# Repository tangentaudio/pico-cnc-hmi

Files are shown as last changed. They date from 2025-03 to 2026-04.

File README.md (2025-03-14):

# pico-cnc-hmi
Open source and open hardware HMI for LinuxCNC using USB Raw HID on a Raspberry Pi Pico 2.

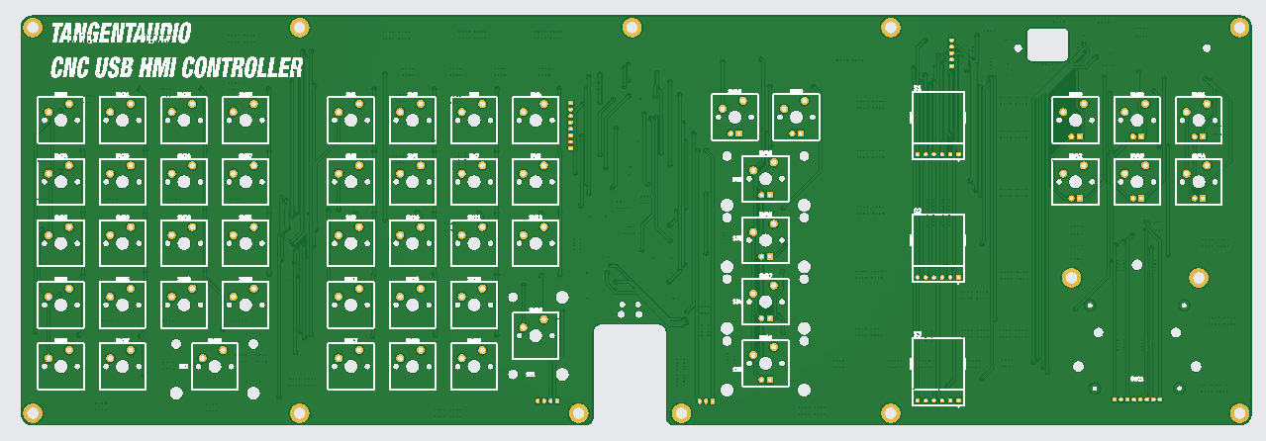
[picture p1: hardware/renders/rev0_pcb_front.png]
REV0 PCB Render Front

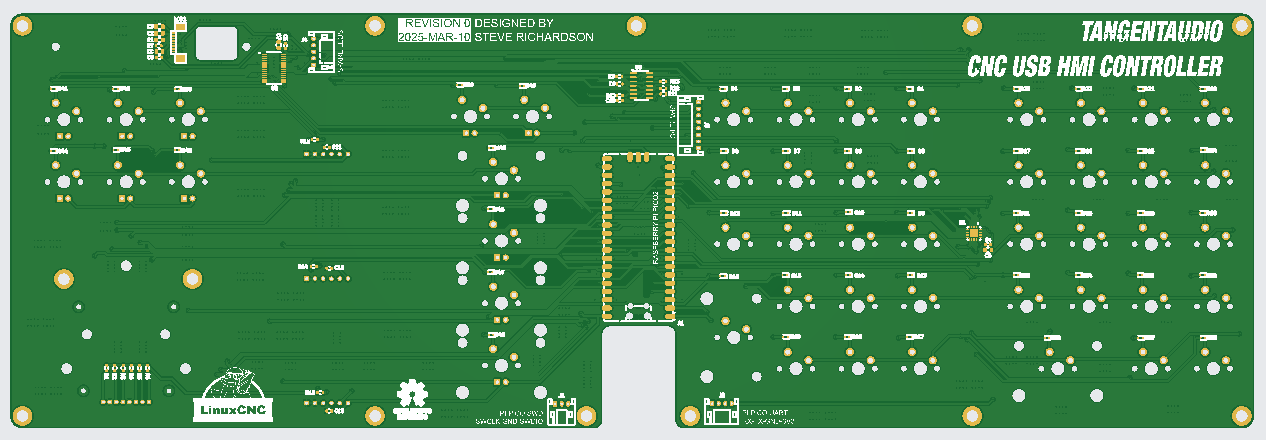
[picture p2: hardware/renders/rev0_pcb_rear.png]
REV0 PCB Render Rear


# News

- rev0 PCB sent to fabrication on 2025-MAR-10.

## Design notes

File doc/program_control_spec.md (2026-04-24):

# Pico CNC HMI — Program Control Specification

## 1. Overview

This document specifies the desired behavior of the four program control buttons
on the HMI: **STOP**, **PAUSE**, **CYCLE START**, and **SINGLE STEP**. It also
covers their interaction with LinuxCNC's mode and interpreter state.

> [!IMPORTANT]
> **Design Principle:** The HMI must never initiate unexpected machine motion.
> Only CYCLE START may start or resume motion. All other transitions leave the
> machine stationary.

---

## 2. LinuxCNC State Primer

### Modes (task_mode)
| Value | Name | Notes |
|---|---|---|
| 1 | MANUAL | Jog, home |
| 2 | AUTO | Program execution, step, pause, resume |
| 3 | MDI | Manual Data Input (Probe Basic uses this frequently) |

### Task State (s.state / RCS status)
| Constant | Meaning |
|---|---|
| `RCS_DONE` | Task is idle (not executing anything) |
| `RCS_EXEC` | Task is executing (program running, stepping, or paused mid-program) |
| `RCS_ERROR` | Task encountered an error |

> [!IMPORTANT]
> `s.state == RCS_EXEC` remains true even when a program is **paused**.
> This is how QtPyVCP detects "paused mid-program" vs "truly idle":
> `RCS_EXEC and s.paused`.

### Interpreter States (interp_state)
| Value | Name | Meaning |
|---|---|---|
| 1 | IDLE | No program activity |
| 2 | READING | Interpreter is reading/executing G-code lines |
| 3 | PAUSED | Program paused (by AUTO_PAUSE or between steps) |
| 4 | WAITING | Waiting for motion/IO to complete |

### Pause-Related Fields
| Field | Type | Meaning |
|---|---|---|
| `s.paused` | bool | Motion trajectory paused (`motion.traj.paused`) |
| `s.task_paused` | int | Task-level paused flag (`task.task_paused`) |

> [!WARNING]
> `interp_state == INTERP_PAUSED` is NOT the only way LinuxCNC can be "paused."
> After an `AUTO_STEP`, the interpreter may settle in `INTERP_READING` or
> `INTERP_WAITING` with `task_paused=1` and `paused=True`. Our code must use
> `s.paused` (or `s.state == RCS_EXEC and s.paused`) as the canonical "is it
> paused?" check, NOT `interp_state == INTERP_PAUSED`.

### Key LinuxCNC Commands
| Command | Effect |
|---|---|
| `c.auto(AUTO_RUN, 0)` | Start program from line 0 (continuous) |
| `c.auto(AUTO_STEP)` | Execute one block then pause |
| `c.auto(AUTO_PAUSE)` | Pause a running program (immediate deceleration) |
| `c.auto(AUTO_RESUME)` | Resume from pause (continuous) |
| `c.abort()` | Abort program execution |
| `c.mode(MODE_AUTO)` | Switch to AUTO mode (required before program commands) |

---

## 3. HMI State Model

### The Step-Mode Question

LinuxCNC does **not** expose a "step mode" flag. From LinuxCNC's perspective,
`AUTO_STEP` is a one-shot command: "execute one block, then pause." There is no
persistent "step mode" state in LinuxCNC.

**QtPyVCP's approach (Probe Basic's GUI):** Each button press is a simple,
stateless command:
- **Step button** → `CMD.auto(AUTO_STEP)` (no flag, no toggle)
- **Run button** → if `paused`: `AUTO_RESUME`, else: `AUTO_RUN`
- **Pause button** → `AUTO_PAUSE`

Probe Basic does NOT track a step-mode flag. Each step press just advances one
block. The "run" button always resumes continuously. This is simple and robust.

**Our HMI constraint:** We have a dedicated STEP button that we want to act as
a modal toggle (enter/exit step mode). This is a UX choice that goes beyond what
LinuxCNC natively models. We need `hmi_step_mode` because:
1. We want CYCLE START to advance one block when "in step mode" vs resume
   continuously when "not in step mode"
2. We want distinct LED states for step mode vs paused

**Accepted trade-off:** `hmi_step_mode` is HMI-local state that can desync from
LinuxCNC (e.g., on USB reconnect, or if Probe Basic's GUI is used concurrently).
It resets to `False` on reconnect (safe default: resume continuously).

### Logical State Derivation

Rather than mixing raw LinuxCNC fields throughout the command handlers, compute
a single logical state once per cycle:

```python
def compute_logical_state():
    if s.interp_state == INTERP_IDLE:
        return 'IDLE'
    elif hmi_step_mode:
        return 'STEPPING'
    elif s.paused:       # covers interp PAUSED, READING+paused, WAITING+paused
        return 'PAUSED'
    else:
        return 'RUNNING'
```

This collapses the combinatorial explosion into 4 states that map cleanly to
button actions and LED states.

### State Transition Diagram

```
                       STEP from IDLE
                       (sets step_mode=true,
                        issues AUTO_STEP →
┌──────────────┐        executes 1st block)
│     IDLE     │─────────────────────────────┐
│  (STOP lit)  │                             │
└──────┬───────┘                             ▼
       │                              ┌──────────────┐
       │ CYCLE START                  │  STEPPING    │◄──┐
       │ (AUTO_RUN)                   │(STEP+START   │   │
       ▼                              │  blink)      │   │
┌──────────────┐                      └──┬───┬───────┘   │
│   RUNNING    │                        │   │            │
│  (START lit) │          CYCLE START   │   │            │
└──┬───────────┘          (AUTO_STEP) ──┘   │            │
   │                                        │            │
   │ PAUSE                    STEP          │            │
   │ (AUTO_PAUSE)             (toggle off → │            │
   ▼                           step_mode=   │            │
┌──────────────┐               false)       │            │
│    PAUSED    │◄───────────────────────────┘            │
│ (PAUSE blink)│                                         │
└──┬───────────┘                                         │
   │                                                     │
   │ STEP from PAUSED                                    │
   │ (sets step_mode=true, NO command issued,            │
   │  awaits CYCLE START to advance)                     │
   └─────────────────────────────────────────────────────┘

   STOP from any state → IDLE  (c.abort, step_mode=false)
```

**Key distinction:**
- **STEP from IDLE** → enters step mode AND auto-starts first block (`AUTO_STEP`)
- **STEP from PAUSED** → enters step mode only (no motion until CYCLE START)

---

## 4. Button Behavior Specification

### 4.1 STOP

| Aspect | Specification |
|---|---|
| **Detection** | Level-based (held = continuous abort) — safety |
| **Pre-condition** | Always active (even during e-stop for re-abort) |
| **Action** | `c.abort()`, clear `hmi_step_mode` |
| **Post-state** | IDLE |
| **Notes** | Most authoritative button. Overrides all other states. |

### 4.2 CYCLE START

| Aspect | Specification |
|---|---|
| **Detection** | Rising-edge only |
| **Pre-condition** | Machine homed |

**Behavior by logical state:**

| Logical State | Action | Result |
|---|---|---|
| IDLE | Ensure MODE_AUTO, `AUTO_RUN(0)` | Start program continuously |
| RUNNING | No effect | Already running |
| PAUSED | `AUTO_RESUME` | Resume continuous run |
| STEPPING | Guard: only if `s.current_vel == 0`; ensure MODE_AUTO, `AUTO_STEP` | Advance one block |

> [!WARNING]
> **Step stacking guard:** In STEPPING state, CYCLE START is ignored when
> `s.current_vel > 0` (machine is still executing the previous block). This
> prevents hammering the button from queueing multiple steps.
> 
> **Note:** `s.paused` cannot be used here — it stays `True` throughout step
> mode execution. `s.inpos` cannot be used either — it stays `False` after
> mid-motion PAUSE. `s.current_vel` reliably indicates actual machine motion.

> [!IMPORTANT]
> CYCLE START is the **only** button that initiates machine motion.
> In PAUSED state, it **always** resumes continuously — the user must press
> STEP first to enter step mode if they want single-stepping.

### 4.3 PAUSE

| Aspect | Specification |
|---|---|
| **Detection** | Rising-edge only |
| **Pre-condition** | Machine homed |

| Logical State | Action | Result |
|---|---|---|
| RUNNING | `AUTO_PAUSE` | Pause program |
| PAUSED | No effect | Already paused |
| STEPPING | `AUTO_PAUSE` if `not s.paused` | Halt mid-block immediately |
| IDLE | No effect | Nothing to pause |

> [!IMPORTANT]
> PAUSE must **always** work as an immediate motion halt. Operators learn this
> as a safety reflex — it must not silently fail in step mode or any other mode.

### 4.4 SINGLE STEP

| Aspect | Specification |
|---|---|
| **Detection** | Rising-edge only |
| **Pre-condition** | Machine homed |

| Logical State | Action | Result |
|---|---|---|
| IDLE | Set step_mode=true, ensure MODE_AUTO, `AUTO_STEP` | Enter step mode from idle |
| PAUSED | Set step_mode=true | Enter step mode (next CYCLE START steps) |
| RUNNING | No effect | Must PAUSE first |
| STEPPING | Set step_mode=false | Exit step mode → PAUSED |

> [!NOTE]
> When exiting step mode (toggling off), the program remains paused. The user
> must press CYCLE START to resume continuous execution. This prevents accidental
> motion on a toggle.

### 4.5 HOME ALL CHORD (STOP + CYCLE START)

| Aspect | Specification |
|---|---|
| **Detection** | Firmware-level: both STOP and CYCLE START held simultaneously for 2 seconds |
| **Pre-condition** | Machine enabled, out of e-stop, NOT homed |
| **Action** | `hmi.home-all` HAL pin pulsed, `c.home(-1)` called directly |
| **Post-state** | Homing sequence begins on all joints |

**Firmware feedback during countdown:** STOP LED fast-blinks (4 Hz). Releasing
either button before 2 seconds cancels the chord.

**On fire:** Both STOP and RUN LEDs flash full brightness.

**Guard:** The chord is silently ignored if the machine is in e-stop, not enabled,
or already homed. Once homed, STOP and CYCLE START return to their normal
functions as defined above.

> [!NOTE]
> This is implemented entirely in the firmware (chord detection + LED countdown).
> hmi.py reads the `home_all` bit from the HID IN packet and issues the LinuxCNC
> commands. The chord uses bits 0x40 in `motion_cmd`.

---

## 5. LED Specification

### LED Assignments
| LED Index | Label | Button |
|---|---|---|
| 8 | STEP | Single Step |
| 9 | PAUSE | Pause |
| 10 | STOP | Stop |
| 11 | RUN | Cycle Start |

### LED States by Logical State

| Logical State | STEP (8) | PAUSE (9) | STOP (10) | RUN (11) |
|---|---|---|---|---|
| **Not homed** | Off | Off | Slow blink | Off |
| **IDLE** | Off | Off | Solid | Off |
| **RUNNING** | Off | Off | Off | Solid |
| **PAUSED** | Off | Blink | Off | Off |
| **STEPPING (waiting)** | Blink | Off | Off | Blink |
| **STEPPING (executing)** | Solid | Off | Off | Solid |
| **E-stop / Disabled** | Off | Off | Off | Off |

> [!NOTE]
> "Stepping (waiting)" vs "Stepping (executing)" is driven by
> **`s.current_vel`**: when velocity is zero the machine is at rest (blink),
> when velocity is non-zero a block is executing (solid).
>
> **Rejected alternatives (tested 2026-04-24):**
> - `s.paused`: stays `True` throughout step mode execution — completely
>   unusable for LED distinction.
> - `s.inpos`: works for normal step cycles but stays `False` after a
>   mid-motion PAUSE, causing incorrect "executing" indication when stopped.

---

## 6. Mode Switching

### Auto-Switch to AUTO
Program control commands (CYCLE START, STEP from IDLE) require `MODE_AUTO`.
The HMI transparently switches to AUTO before issuing the command.

### Auto-Switch to MANUAL
When the jog wheel moves and `interp_state == IDLE`, the HMI auto-switches
to `MODE_MANUAL`. This covers the common case of being stuck in MDI/AUTO
after a program ends.

### Jog Controls Gating
- **Jog LEDs** (axis/increment): visible in MANUAL, MDI, or AUTO+IDLE
- **Jog motion**: only sent to HAL when in MANUAL mode
- **Jog config** (axis/increment selection): always forwarded (config, not motion)

---

## 7. Edge Detection Rules

| Button | Detection | Rationale |
|---|---|---|
| STOP | Level (held) | Safety — continuous abort while held |
| CYCLE START | Rising edge | Prevent repeated run/step on hold |
| PAUSE | Rising edge | Prevent repeated pause commands |
| STEP | Rising edge | Prevent repeated toggle |
| COOLANT | Rising edge | Toggle |
| OPT STOP | Rising edge | Toggle |
| HOME CHORD | Rising edge (2s hold) | Special: chord timing in firmware |

---

## 8. Analysis of Current Implementation vs This Spec

### 8.1 Bug: Step→Resume Broken (CYCLE START dead after exiting step mode)

**Symptom:** After exiting step mode (STEP toggle off), CYCLE START has no effect.

**Root cause:** When `hmi_step_mode` is toggled off, LinuxCNC is "paused" but
`interp_state` may be `INTERP_READING` (2) — not `INTERP_PAUSED` (3).
The CYCLE START resume path only checks `interp_state == INTERP_PAUSED`,
missing the READING+paused case entirely.

**Fix per this spec:** The `compute_logical_state()` function uses `s.paused`
(not `interp_state == INTERP_PAUSED`) to detect PAUSED. The CYCLE START handler
for PAUSED state issues `AUTO_RESUME` regardless of `interp_state`. This matches
how QtPyVCP does it:
```python
# QtPyVCP program_actions.py line 129:
elif STAT.state == linuxcnc.RCS_EXEC and (STAT.paused or interp_paused):
    CMD.auto(linuxcnc.AUTO_RESUME)
```

### 8.2 Architectural Comparison with QtPyVCP

QtPyVCP's approach is simpler because it has **separate buttons** for Step and
Run. Each button is a stateless action: Step always steps, Run always
runs/resumes. No toggle state needed.

Our HMI has a single CYCLE START button that must do different things depending
on context (step vs resume). This forces us to maintain `hmi_step_mode`. The
trade-off is acceptable — we just need to keep the dispatch clean.

### 8.3 Key Lessons from QtPyVCP

1. **Use `s.paused` not `interp_state`** for pause detection
2. **Use `s.state == RCS_EXEC`** to know if a program is active
3. **`AUTO_STEP` works from any paused state** — no special interp_state checks
4. **`AUTO_RESUME` works from any paused state** — same
5. **Step is stateless in LinuxCNC** — our modal toggle is an HMI-layer concept

---

## 9. Resolved Design Decisions

**Q1: PAUSE during step mode?**
**Decision: Allowed.** PAUSE must always work as an immediate motion halt —
operators learn this as a safety reflex and it must not silently fail in any
mode. LinuxCNC's `emcTrajPause()` immediately decelerates mid-block.
`AUTO_PAUSE` is issued unconditionally in STEPPING state — it is a safe
no-op when the machine is already at rest. After pausing mid-step, the LEDs
blink (vel=0). The next CYCLE START issues `AUTO_STEP` which continues from
where it stopped — LinuxCNC handles this natively.

**Q2: STEP during RUNNING (continuous)?**
**Decision: No effect (must PAUSE first).** Keeps the interaction model simple.

**Q3: Step-mode LED and guard signal?**
**Decision: Resolved — use `s.current_vel`.** Tested 2026-04-24:
- `s.paused` stays `True` throughout step mode execution (completely unusable).
- `s.inpos` works for normal step cycles but stays `False` after mid-motion
  PAUSE, preventing further stepping and showing incorrect LED state.
- `s.current_vel` reliably transitions between 0 (at rest) and >0 (executing)
  in all tested scenarios: step-from-idle, pause→step, pause-mid-step→resume.
  Used for both the LED blink/solid distinction and the step stacking guard.

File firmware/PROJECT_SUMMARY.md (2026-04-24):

# Pico CNC HMI Firmware - Project Summary

Date: 2026-04-20 (last updated 2026-04-21 after SDK 2.2.0 + LVGL 9.5.0 upgrade)
Scope: Source-based review of firmware plus LinuxCNC host bridge script.

Current maturity (confirmed by user):
- Early bring-up / debug / proof-of-concept state.
- Project has been dormant for about a year and this document is intended as a memory-refresh baseline.
- Current implementation details are provisional and may change substantially as requirements and hardware usage are refined.

## 1. What This Project Appears To Do

This firmware targets Raspberry Pi Pico 2 and implements a CNC human-machine interface (HMI).

Primary functions observed in code:
- Read hardware controls: keypad matrix, GPIO key events, jog wheel/shuttle, and rotary encoders.
- Drive outputs: simple LEDs (TLC59116), RGB ring LEDs (WS2812), optional OLED display (SH1122 via LVGL).
- Exchange runtime state with host CNC software over USB HID.
- Emulate keyboard key events over a second USB HID keyboard interface.

## 1.1 Physical Device Layout (User-Described, In Progress)

Overall form factor:
- Roughly the footprint of a standard 101-key keyboard.
- Uses keyboard-style keys plus rotary and jog/shuttle controls.
- Includes monochrome display, several single-color key LEDs, and RGB LED rings around rotary knobs.

Section-by-section description (left to right, currently captured):
- Section A (left): key-only area, 4 columns x 5 rows.
- Section A exception: lower-right position uses one double-width horizontal key replacing two standard keys.
- Intended use for Section A: future G-code / MDI keypad functions.
- Section A key labels/functions: currently TBD.

- Physical gap between sections.

- Section B (next): key-only area, 4 columns x 5 rows.
- Section B exception: lower-right area combines two vertically stacked keys into one extra-tall key.
- Intended use for Section B: roughly numeric keypad + math operators + previous/next + enter, aligned with current key map in code.

- Section C (to the right of B, with a larger gap): 5 rows tall, mostly dedicated machine-control keys with LED status.
- Section C top row: two buttons, M1 Stop and Coolant, each with LED toggle/status indication.
- Section C row 2: Single Step with LED.
- Section C row 3: Pause with LED.
- Section C row 4: Stop with LED.
- Section C row 5: Cycle Start with LED.

- Section D (to the right of C, small gap): three continuous rotary encoders arranged vertically.
- Each Section D encoder has a surrounding RGB LED ring covering nearly 360 degrees with a small wedge gap at the bottom.
- Section D value model: conceptually 0-100%, with the wedge gap representing the discontinuity point.

- Section E (rightmost, final section): display at the top, with a grid of keys below, each key having LED feedback.
- Section E top key row: jog increment selection with values 0.010 inch, 0.001 inch, and 0.0001 inch.
- Section E next key row: axis selection keys X, Y, and Z.
- Section E lower control: special jog/shuttle knob with two concentric rings.
- Section E outer ring behavior: spring-return to center, supports continuous jogging with variable degree/speed.
- Section E inner ring behavior: traditional incremental encoder wheel for stepped jog moves.
- Both concentric controls operate on the currently selected movement axis.

Notes:
- This layout documentation is intentionally evolving and may be revised as ergonomics and workflows are refined.
- Additional sections to be appended as provided.

## 1.2 Operator Flow Map (Current Behavior + Planned Intent)

This map is intended to connect physical controls to operational workflows.
Items are marked as either current (observed in code) or planned/TBD.

Flow A: Manual jog workflow (current core behavior)
1. Operator selects jog increment in Section E (0.010 / 0.001 / 0.0001 inch).
2. Operator selects axis in Section E (X / Y / Z).
3. Operator moves jog controls in Section E:
- Outer spring-return ring drives continuous jog intent (variable level).
- Inner encoder drives incremental jog intent.
4. Firmware packages axis + step + jog/shuttle data into HID input report.
5. LinuxCNC host bridge applies values via HAL and command interfaces.

Flow B: Program execution control workflow (current core behavior)
1. Operator presses Section C controls (Cycle Start / Stop / Pause / Single Step / M1 Optional Stop / Coolant).
2. Firmware maps these to motion command bits and sends them to host.
3. Host bridge translates command bits to LinuxCNC commands:
- Stop -> abort
- Cycle Start -> AUTO_RUN (from IDLE), AUTO_RESUME (from normal pause), AUTO_STEP (in step mode)
- Pause -> AUTO_PAUSE (gates: READING/WAITING, not step mode, not already paused)
- Single Step -> AUTO_STEP from IDLE (enters step mode; Cycle Start then advances each step)
- M1 Optional Stop -> toggle c.set_optional_stop() on press edge
- Coolant -> toggle c.flood(FLOOD_ON/OFF) on press edge
4. Host state update returns over HID output report.
5. Firmware updates Section C LED feedback according to machine/interpreter state.

Flow C: Override tuning workflow (current core behavior)
1. Operator adjusts three Section D rotary encoders.
2. Firmware normalizes encoder segment values and sends knob1/2/3 in HID input report.
3. Host bridge maps values to feedrate, rapidrate, and max velocity overrides.
4. Firmware updates encoder RGB ring displays to indicate current values/state.

Flow D: Keyboard/MDI-style input workflow (hybrid: current + planned)
1. Section B numeric/operator keys are mapped to keyboard/HID behavior in current code.
2. Section A is intended for G-code/MDI-centric entry but function map remains TBD.
3. Host-side integration path for finalized MDI workflow is pending requirements definition.

Flow E: Display-assisted operation workflow (bring-up only)
1. Display currently serves diagnostics/bring-up feedback.
2. Final operator UI pages, alert model, and steady-state information architecture are TBD.

Design note:
- Because this is early-stage development, all flows are expected to evolve.
- Use this map as a working model for alignment, not as a fixed contract.

## 1.3 State and LED Behavior Snapshot (As Left In Last Effort)

This section captures observed LED/ring behavior from current firmware as a historical baseline.
It is intentionally not treated as final product behavior.

Machine availability behavior:
- When machine link is not alive, firmware turns off selection LEDs, interp LEDs, and all three RGB rings.
- On receipt of host traffic, machine-alive state resumes and normal state-driven LED behavior continues.

Section E selection LEDs (manual mode only):
- Increment LEDs (indices 0,1,2): one active at low brightness based on selected increment.
	- Increment 1 -> LED 0 on
	- Increment 2 -> LED 1 on
	- Increment 3 -> LED 2 on
- Axis LEDs (indices 3,4,5): one active at low brightness based on selected axis.
	- Axis 1 -> LED 3 on
	- Axis 2 -> LED 4 on
	- Axis 3 -> LED 5 on
- Outside manual mode or when estop/disabled, these selection LEDs are forced off.

Section C program-control LEDs (interp state presentation, 2026-04-20 milestone):
- LED index to physical key mapping:
	- LED 6 = M1 Optional Stop (0x3d): solid on = optional stop enabled, off = disabled
	- LED 7 = Coolant/Flood (0x3e): solid on = flood on, off = flood off
	- LED 8 = Single Step (0x33)
	- LED 9 = Pause (0x34)
	- LED 10 = Stop (0x35)
	- LED 11 = Cycle Start (0x36)
- Interp state presentation (LEDs 8-11, gated on enabled and not estop):
	- INTERP_IDLE: LED 10 (Stop) solid
	- INTERP_READING, normal run: LED 11 (Cycle Start) solid
	- INTERP_READING, step mode: LED 8 (Step) + LED 11 (Cycle Start) solid if !paused (executing), blink if paused (waiting)
	- INTERP_PAUSED, normal run (AUTO_PAUSE): LED 9 (Pause) blink
	- INTERP_PAUSED, step mode: LED 8 + LED 11 blink (waiting for Cycle Start) or solid (machine moving)
	- INTERP_WAITING, normal run: LED 11 solid
	- INTERP_WAITING, step mode: LED 8 + LED 11 blink or solid (same as PAUSED step logic)
	- estop or disabled: all off
- M1 and Coolant LEDs (6 and 7) always follow host state regardless of estop/enabled.

Section D RGB encoder rings:
- Ring 0 follows encoder 1 value and uses color urgb(0x3f, 0x1f, 0x00).
- Ring 1 follows encoder 2 value and uses color urgb(0x00, 0x3f, 0x3f).
- Ring 2 follows encoder 3 value and uses color urgb(0x3f, 0x00, 0x3f).
- Rings update on encoder change events and are cleared when machine link is not alive.

Presentation caveat:
- LED index to physical legend mapping should be treated as provisional until front-panel legend/function lock is completed.

## 1.4 Control Index Cross-Reference (Current Snapshot)

Purpose:
- Avoid ambiguity like "LED 10" by tying matrix code, LED index, physical control intent, and host action together.
- This table reflects current code and should be treated as a baseline snapshot, not a locked final design.

Key/LED mapping backbone:
- key_to_led_map order in firmware is:
	- [0]=0x2f, [1]=0x30, [2]=0x37, [3]=0x38, [4]=0x39, [5]=0x3a,
	- [6]=0x3d, [7]=0x3e, [8]=0x33, [9]=0x34, [10]=0x35, [11]=0x36.

Section E and Section C controls (mapped):

| Physical Intent | Matrix Code | LED Index | Firmware Meaning | Host/HID Meaning |
|---|---:|---:|---|---|
| Jog increment 0.010 in | 0x2f | 0 | selected_increment = 1 | pkt.step = 100 (-> 0.010 in in hmi.py) |
| Jog increment 0.001 in | 0x30 | 1 | selected_increment = 2 | pkt.step = 10 (-> 0.001 in in hmi.py) |
| Jog increment 0.0001 in | 0x37 | 2 | selected_increment = 3 | pkt.step = 1 (-> 0.0001 in in hmi.py) |
| Axis X select | 0x38 | 3 | selected_axis = 1 | pkt.axis = 1 |
| Axis Y select | 0x39 | 4 | selected_axis = 2 | pkt.axis = 2 |
| Axis Z select | 0x3a | 5 | selected_axis = 3 | pkt.axis = 3 |
| M1 Optional Stop | 0x3d | 6 | motion_cmd bit 0x10 (edge-detected) | toggle c.set_optional_stop(); LED = s.optional_stop |
| Coolant/Flood | 0x3e | 7 | motion_cmd bit 0x20 (edge-detected) | toggle c.flood(ON/OFF); LED = bool(s.flood) |
| Single Step | 0x33 | 8 | motion_cmd bit 0x08 | enters step mode from IDLE; Cycle Start advances steps |
| Pause | 0x34 | 9 | motion_cmd bit 0x04 | AUTO_PAUSE (gated: READING/WAITING, not step mode) |
| Stop | 0x35 | 10 | motion_cmd bit 0x02 | always c.abort() |
| Cycle Start | 0x36 | 11 | motion_cmd bit 0x01 | AUTO_RUN/RESUME/STEP depending on state |

Section D encoder and ring mapping:

| Physical Intent | Source | Visual Channel | Firmware Field | Host Action |
|---|---|---|---|---|
| Override knob 1 | encoder 1 | RGB ring 0 | pkt.knob1 | hmi.py feedrate override |
| Override knob 2 | encoder 2 | RGB ring 1 | pkt.knob2 | hmi.py rapid override |
| Override knob 3 | encoder 3 | RGB ring 2 | pkt.knob3 | hmi.py max velocity override |

Special jog/shuttle mapping (Section E concentric control):

| Physical Control | Source Field | Host Pin/Use |
|---|---|---|
| Inner jog wheel (incremental) | pkt.jog | HAL jog.inner.value |
| Outer shuttle ring (spring return) | pkt.shuttle | HAL jog.outer.value and jog.is-shuttling |

Open labeling note:
- All Section C keys (0x3d through 0x36) are now fully implemented and locked in. No open physical-to-code mapping ambiguity remains for Section C.

## 1.5 Deployment Context and Primary Use Cases (Confirmed)

System context:
- This HMI is not intended to run standalone.
- It is intended to operate alongside a LinuxCNC GUI on a touchscreen system.

Primary GUI targets:
- Probe Basic (QtPyVCP).
- A custom QtVCP GUI derived in part from QtDragon.

Operational goal:
- Combined HMI + touchscreen interaction should replace keyboard and mouse for most machine operation.
- Target coverage is roughly 95 percent of typical usage.
- Likely exception area: editing complex G-code programs, where full keyboard/mouse workflows may still be needed.

Design implication for future work:
- Control mapping, display content, and host integration should prioritize fast operational workflows and minimize dependency on desktop-style input devices.

## 2. Build and Feature Flags

Top-level CMake options:
- ENABLE_DISPLAY: enables LVGL + SH1122 OLED path.
- ENABLE_USB: enables TinyUSB HID interfaces and USB task.

Key dependencies used directly:
- Pico SDK 2.2.0
- FreeRTOS kernel
- TinyUSB 0.18.0 (bundled with SDK 2.2.0)
- LVGL 9.5.0 (optional, vendored at firmware/lvgl/)

### 2.2 Build Quirks (2026-04-21 upgrade notes)

The following issues were encountered upgrading from SDK 2.1.1 + LVGL 9.3.0 and are now addressed in CMakeLists.txt.
Document them here so a fresh clone doesn't repeat the debugging.

**Clean build required after LVGL version change**
LVGL uses `file(GLOB_RECURSE ...)` to collect its source list. After a version upgrade, stale .o files from the
old version persist in the build tree and cmake's dependency tracking carries them into the new build.ninja.
Always wipe the build directory after changing the LVGL submodule version:
```
rm -rf build/ && mkdir build && cd build && cmake -G Ninja ..
```

**LVGL 9.5.0: lv_conf.h discovery changed**
In 9.5.0, LVGL no longer finds `lv_conf.h` by looking in `${CMAKE_BINARY_DIR}/lvgl/`.
Instead, use the `LV_BUILD_CONF_DIR` cache variable set before `add_subdirectory(lvgl)`.
Must be declared with `CACHE PATH "" FORCE` so it overrides the cached default on a clean configure:
```cmake
set(LV_BUILD_CONF_DIR ${CMAKE_CURRENT_SOURCE_DIR}/port/lvgl CACHE PATH "" FORCE)
```

**LVGL 9.5.0: custom.cmake ninja loop**
LVGL 9.5.0 registers `lvgl/env_support/cmake/custom.cmake` as a cmake input dependency, but does not
include this file in the repository (it is an optional user-customization hook). When the file doesn't
exist, ninja sees its phony output as perpetually dirty and loops re-running cmake indefinitely.
CMakeLists.txt now creates this file automatically with `file(TOUCH ...)` before `add_subdirectory(lvgl)`.

**SDK 2.2.0: new pico_platform_common module**
SDK 2.2.0 split platform common headers into a new module `pico_platform_common`. Any library that
indirectly pulls in Pico headers (LVGL does, via FreeRTOS portmacro.h) needs this include added manually
since it is not automatically propagated through the LVGL cmake target:
```
${PICO_SDK_PATH}/src/rp2_common/pico_platform_common/include/
```
This is added to the `target_include_directories(lvgl ...)` block in CMakeLists.txt.

## 2.1 2026 SDK Landscape Audit (For This Project)

Current project baseline:
- Project is configured for SDK 2.1.1 in CMake/tooling metadata.
- Current TinyUSB baseline via SDK 2.1.1 is TinyUSB 0.18.0.

Upstream changes since this project was last active:
- pico-sdk 2.2.0 is available (release date 2025-07-29) with additional bug fixes and documentation improvements.
- TinyUSB has continued advancing (latest visible release: 0.20.0), including multiple stack and controller-driver fixes over 0.18.0.

What appears most relevant to this firmware:
- USB stack evolution: TinyUSB API and behavior have continued to mature (device/host internals, endpoint handling, stability fixes).
- FreeRTOS + RP2350 alignment: SDK notes emphasize keeping FreeRTOS import/port files current for RP2350-era integration.
- Runtime and IRQ quality improvements in newer SDK versions reduce edge-case risk in interrupt-heavy and RTOS-heavy projects.

Assessment for your USB concern:
- Yes, the landscape has improved versus a year ago, especially around TinyUSB maturity and RP2350 ecosystem integration.
- Your current code already uses the newer `tusb_init(rhport, init_struct)` style, which aligns with modern TinyUSB direction.

Project-specific modernization opportunities (no behavior changes yet):
1. SDK bump trial branch
- Evaluate upgrade from 2.1.1 to 2.2.x in a dedicated branch and recreate the build directory.

2. USB descriptor hygiene
- Review USB configuration descriptor attributes and power declaration for strict spec conformance.

3. HID robustness
- Add explicit handling/logging for full USB OUT queue conditions in `tud_hid_set_report_cb`.
- Check return status from generic HID IN report send path and track dropped frames.

4. Protocol observability
- Add counters for rx packets, tx packets, queue overflows, parse rejects, and heartbeat timeouts.

5. FreeRTOS import freshness
- Re-validate `FreeRTOS_Kernel_import.cmake` and port path assumptions against current upstream guidance for RP2350 builds.

Suggested execution order:
- Step 1: SDK/toolchain upgrade branch + clean rebuild.
- Step 2: USB smoke tests (enumeration, reconnect, suspend/resume, long-run HID traffic).
- Step 3: Add observability and queue-drop instrumentation.
- Step 4: Only then consider protocol/interface refactors.

## 3. Runtime Architecture

Main initialization sequence (high level):
1. Initialize UART stdout.
2. Optional USB stack init.
3. Pulse peripheral reset pin (GPIO22).
4. Optional display init.
5. Init shared I2C bus.
6. Init task objects (encoder, matrix, LED, optional display).
7. Create FreeRTOS tasks and start scheduler.

Main tasks observed:
- MATRIX_TASK: polls TCA8418 event FIFO and pushes key/gpio events.
- ENCODER_TASK: polls quadrature PIO counters and shuttle GPIO code, pushes value events.
- LED_TASK: processes LED commands for TLC59116 and WS2812.
- DISPLAY_TASK_TIMER / DISPLAY_TASK_HANDLER / DISPLAY_GUI_TASK (optional): LVGL scheduling and UI updates.
- USB_TASK (optional): runs tinyusb tud_task periodically.
- MAIN_TASK: central state machine, consumes matrix/encoder/USB queues and updates LEDs + outbound HID reports.

Inter-task communication:
- FreeRTOS queues are the primary IPC mechanism.
- MAIN_TASK is the orchestrator that translates device events to host HID packets and visual state.

## 4. USB Protocol (Observed)

Two HID interfaces are exposed:
- Generic HID IN/OUT (64-byte report) for CNC state exchange.
- Keyboard HID interface for keycode-style commands.

Observed outbound-to-host fields (input report):
- knob1/2/3, axis, step, jog, shuttle, motion_cmd.

Observed host-to-device fields (output report, header 0xAA):
- heartbeat, estop, enabled, mode, interp_state, feedrate_override, rapidrate_override, maxvel_override.
- feedrate_override and rapidrate_override are segment indices 0–14 encoding the override fraction relative to the configured max.
- maxvel_override is a segment index 0–14 encoding actual velocity via the configured power-law curve.

One-time configuration packet (header 0xAB, sent once on connect):
- max_feed_pct: max feed override ceiling as integer percent (e.g. 150 for 150%)
- max_rapid_pct: max rapid override ceiling as integer percent
- max_vel_x10: configured_maxvel × 10 in LinuxCNC velocity units (e.g. 600 for 60.0 IPM)
- min_vel_x10: configured_maxvel_min × 10
- curve_x100: maxvel power-law exponent × 100 (e.g. 200 for 2.0)
- Purpose: lets the HMI display real units (e.g. "73%" feed, "42.3 IPM") and compute the exact 100%-reset target segment for each knob.
- HMI helper functions: hmi_feed_pct(seg), hmi_rapid_pct(seg), hmi_maxvel_x10(seg), hmi_feed_reset_seg(), hmi_rapid_reset_seg() — all in usb.h.
- Defaults are safe non-zero values so display code works even before config is received.

Behavioral notes:
- Firmware gates many actions on machine alive + not estop + enabled + mode.
- LED state reflects mode/interpreter state and selected axis/increment.
- Encoder presses from matrix GPIO map can trigger smart reset behavior for knob values.

## 4.1 LinuxCNC Host Bridge (Confirmed)

Host side implementation exists in ../linuxcnc/hmi.py and uses:
- python-hid for USB HID communication.
- linuxcnc Python API (stat + command).
- HAL component pins for observability/bridging.

Observed host -> device packet handling:
- Polls LinuxCNC status, increments heartbeat every 500 ms, and sends a 64-byte HID output report when status changes or heartbeat advances.
- Packed payload format: <BBBBBBBBB
	- header (0xAA), heartbeat, estop, enabled, mode, interp_state,
	- feedrate*100, rapidrate*100,
	- maxvel*100/configured_maxvel.

Observed device -> host packet handling:
- Reads 64-byte HID input reports and unpacks first 17 bytes with format <BBBBIiiB.
- Mapping in hmi.py:
	- knob0 -> c.feedrate(knob0/14.0)
	- knob1 -> c.rapidrate(knob1/14.0)
	- knob2 -> c.maxvel(knob2*configured_maxvel/14.0)
	- axis, jog step, jog inner, jog outer are exported to HAL pins.
	- motion_cmd bitmask drives LinuxCNC actions:
		- 0x02 stop -> c.abort()
		- 0x01 start -> AUTO_RESUME if paused else AUTO_RUN from line 1 if idle
		- 0x04 pause -> toggle pause/resume
		- 0x08 step -> AUTO_STEP

Integration implication:
- The 0..14 encoder segmentation is not just a UI choice; it is currently part of host control scaling in hmi.py.

## 5. Hardware Mapping (High-Level)

From code comments and pin constants:
- UART0: GPIO0/1
- SPI OLED: GPIO2/3/4/5
- Jog quadrature: GPIO6/7
- Shuttle code bits: GPIO8-11
- Additional encoders: GPIO12-17
- WS2812: GPIO18
- Key interrupt: GPIO19
- I2C bus: GPIO20/21
- Peripheral reset: GPIO22

## 6. Review Findings (Code Risks)

1. High: encoder set_value scaling appears incorrect and can overflow limits.
- In drivers/encoder.cc, set_value compares and assigns using already-scaled internal limits and multiplies by divisor again, then multiplies once more when storing.
- This likely causes values outside intended bounds for non-unit divisors.

2. High: task creation assert may pass on USB task failure.
- In main.cc, usb_task_status is checked as truthy instead of compared to pdPASS.
- If xTaskCreate returns a non-zero error code, assert can still pass unexpectedly.

3. Medium: LED task appears to spin without delay, potentially wasting CPU and affecting scheduling.
- task_led.cc loops continuously and toggles default LED each pass.
- vTaskDelay is commented out.

4. Medium: machine heartbeat timeout may not arm on first packet if heartbeat value does not change from zero baseline.
- main task marks machine alive on first packet, but timer reset is only tied to heartbeat value changes.
- This could keep machine_alive true longer than intended after link loss in some startup sequences.

## 7. Confirmed Decisions (2026-04-20)

1. Mode semantics
- MODE_AUTO and MODE_TELEOP are intentionally sharing the same motion-command behavior at this stage.

2. Packet hardening
- Header validation (0xAA) is considered nice-to-have, but not required yet during current bring-up.

3. HID discovery strategy
- No additional product/interface filtering is needed yet; current VID-based discovery is acceptable for now.

4. LED task cadence
- LED task timing behavior is acknowledged as likely to change soon, but no code changes are requested at this time.

5. Display scope
- Display is currently true bring-up only; final UI scope and usage are not defined yet.

## 8. Suggested Next Validation Steps

- Add a short protocol note (single source of truth) for both packet structs and scaling constants shared by firmware and hmi.py.
- Add small unit/integration checks around encoder scaling and packet conversion.
- Validate FreeRTOS task stack sizes under display + USB load.
- Confirm intended heartbeat timeout and startup behavior, given host heartbeat period of 500 ms.
- Revisit header validation, HID filtering, and LED scheduler behavior when transitioning from bring-up to stabilization.

## 9. Improvement Opportunities (Design Is Intentionally Flexible)

These are suggestions, not required immediate changes.

1. Define a versioned HID protocol contract
- Add protocol version and capability bits in packet header.
- Reserve bytes for future fields and compatibility.
- Keep one canonical spec file and generate shared constants where practical.

2. Separate transport, domain state, and UI policy
- Keep USB packet encode/decode logic isolated from machine-state logic.
- Keep LED/display policy in a dedicated layer to simplify feature iteration.
- This makes future UI/UX changes less risky for transport/control behavior.

3. Harden task timing and CPU budgeting before feature growth
- Add explicit cadence for LED/background tasks.
- Confirm priority and stack sizing with trace/telemetry snapshots.
- This reduces surprise regressions as display and interaction logic expand.

4. Improve observability for bring-up
- Add structured debug counters: packet RX/TX rate, queue depth high-water marks, timeout counts.
- Add optional lightweight status dump command/report mode for field debugging.

5. Clarify state-machine contracts
- Document allowed transitions for estop/enabled/mode/interp combinations.
- Define precedence when host state and local input conflict.
- This helps keep behavior consistent during future refactors.

6. Make host bridge evolution safer
- Consider explicit device selection (serial/product/interface) when moving past single-device bring-up.
- Add basic exception/backoff strategy in host loop for long-run stability.

7. Prepare for display roadmap uncertainty
- Treat current display as diagnostics-first.
- Define small, testable display data model independent of final screen layout.

## 10. USB Code Debt Audit: Hacks and Workarounds to Undo

This section catalogues specific things in the USB code that were put in place because the stack was
immature, the right pattern was unclear, or template code was never cleaned up. Each item notes what
was done, why it is suboptimal, and what the correct resolution is. Items are ordered from highest to
lowest impact.

---

### HACK-1: CFG_TUSB_OS — CLOSED (not a bug)
**Status**: ~~Deferred~~ → **Closed 2026-04-21 — no change needed**

The original entry assumed `OPT_OS_PICO` was a workaround and `OPT_OS_FREERTOS` was the correct
target. Investigation proved the opposite:

- The Pico SDK's `family.cmake` sets `CFG_TUSB_OS=OPT_OS_PICO` by default for RP2040/RP2350 and
  this is the **intentional, tested choice** — not a fallback.
- `OPT_OS_PICO` uses `osal_pico.h` which wraps `pico/sem.h` primitives. These are explicitly
  designed to be FreeRTOS-interoperable via `configSUPPORT_PICO_SYNC_INTEROP=1` in FreeRTOSConfig.h.
- Attempting to switch to `OPT_OS_FREERTOS` via `set(TINYUSB_OPT_OS OPT_OS_FREERTOS)` in
  CMakeLists.txt caused the HMI to fail to enter offline mode (all LEDs stuck) on hmi.py
  disconnect — a clear regression on the RP2350 SMP FreeRTOS port.
- The old `add_definitions(-DCFG_TUSB_OS=OPT_OS_FREEERTOS)` line (note: typo, double-E) was
  harmless (evaluated to 0, overridden by SDK target definition) and has been removed as noise.
  No replacement needed.

The `USB_TASK` + `vTaskDelay(1)` polling pattern is therefore correct and intentional for this
platform. Latency is bounded at 1ms which is acceptable for a CNC HMI.

---

### HACK-2: usb_hid_periodic() — dead template code never removed
**Files**: `drivers/usb.c`, `drivers/usb.h`
**Category**: leftover example code

What was done:
- `usb_hid_periodic()` was copied from a TinyUSB example. It reads `board_button_read()` and sends
  HID key 'A' when the button is held. It also has a `#ifdef REMOTE_WAKEUP` block.
- The function is declared in `usb.h` and defined in `usb.c` but is **never called anywhere** in the
  actual firmware.

Why it is a hack:
- It is dead code. The keyboard interface is managed in `main_task()` via `tud_hid_n_keyboard_report()`.
  The board button has no hardware wiring on this PCB.
- Its presence is confusing because it contains a keyboard report send path that appears to duplicate
  the one in main.cc.

How to fix:
- Delete `usb_hid_periodic()` from `drivers/usb.c`.
- Remove the declaration from `drivers/usb.h`.
- Remove the `#ifdef REMOTE_WAKEUP` block along with it.

Risk: none — function is unreachable.

---

### HACK-3: Commented-out old API call
**File**: `drivers/usb.c` line 18
**Category**: stale comment

What was done:
- `//tud_init(BOARD_TUD_RHPORT);` is left as a comment showing the old single-argument API.
- The new call directly below it uses the correct `tusb_init(rhport, &dev_init)` form.

How to fix:
- Delete the commented line.

Risk: none.

---

### HACK-4: Generic HID IN report sent without readiness check
**File**: `main.cc`
**Category**: inconsistent defensive coding

What was done:
- The keyboard send path correctly checks `tud_hid_n_ready(ITF_KEYBOARD)` before calling
  `tud_hid_n_keyboard_report()`.
- The generic HID input report send (`tud_hid_report(0, &pkt, sizeof(pkt))`) has no equivalent
  readiness check and its `bool` return value is discarded.

Why it is a hack:
- If the generic HID endpoint is not ready (e.g. host not polling, endpoint stalled, or enumeration
  in progress) the packet is silently lost with no log or counter. The inconsistency between the
  two interfaces suggests the readiness check was added to one path when it caused problems, but the
  fix was not applied uniformly.

How to fix:
```c
if (tud_hid_n_ready(ITF_GENERIC_HID)) {
  if (!tud_hid_report(0, &pkt, sizeof(pkt))) {
    printf("hid_report: send failed\n");  // or increment counter
  }
} else {
  printf("hid_report: endpoint not ready\n");
}
```

Risk: low — purely additive defensive check.

---

### HACK-5: Silent drop in tud_hid_set_report_cb
**File**: `drivers/usb.c`
**Category**: unobservable failure mode

What was done:
- `xQueueSend(usb_out_queue, &pkt, 0)` uses a zero timeout, so if the queue is full the packet is
  dropped silently.
- Using zero timeout is correct here (cannot block in a USB callback), but the drop itself is
  unlogged.

Why it is a hack:
- Dropped host→device packets mean the firmware misses machine state updates. During initial bring-up
  this was probably masked by the host resending state frequently (500ms heartbeat), but it is
  invisible without explicit logging.

How to fix:
```c
if (xQueueSend(usb_out_queue, &pkt, 0) != pdTRUE) {
  // Cannot printf here safely; use a volatile counter instead
  usb_out_queue_drops++;
}
```
Declare `volatile uint32_t usb_out_queue_drops = 0;` and log it periodically from `main_task()`.

Risk: none — purely additive.

---

### HACK-6: usb_in_pkt sends uninitialized padding bytes
**File**: `main.cc`
**Category**: information leak / undefined behavior

What was done:
- `usb_in_pkt` is a union of a packed struct and a 64-byte buffer. The struct occupies 17 bytes
  (knob1, knob2, knob3, axis=4 × uint8, step=uint32, jog=int, shuttle=int, motion_cmd=uint8).
  The remaining 47 bytes are not initialized.
- `tud_hid_report(0, &pkt, sizeof(pkt))` sends all 64 bytes. The uninitialized 47 bytes contain
  whatever was on the stack at that point.

Why it is a hack:
- Sending arbitrary stack contents is both a minor information leak and a source of spurious data if
  the host side ever tries to interpret those bytes in the future.
- By contrast, the receive-side `last_out_pkt` is correctly zeroed with `bzero()` on initialization.

How to fix:
- Add `bzero(&pkt, sizeof(pkt));` immediately before populating the struct fields in `main_task()`.

Risk: none.

---

### HACK-7: g_machine_alive is not volatile
**File**: `main.cc`
**Category**: concurrency correctness

What was done:
- `bool g_machine_alive = false;` is a plain global.
- It is read in `main_task()` (one FreeRTOS task) and written from the heartbeat timer callback
  (which executes in the FreeRTOS timer service task, a different execution context).

Why it is a hack:
- Without `volatile`, the compiler is permitted to cache the value in a register and not re-read it
  from memory on each loop iteration in `main_task()`. In practice GCC at -O0/-O1 usually re-reads
  globals, but at -O2 or with LTO this can bite.
- Writing from a timer callback and reading from a task without any FreeRTOS synchronization
  primitive is technically a data race. For a single bool it is safe in practice on RP2040 (aligned
  single-byte write is atomic), but it should be declared `volatile` to make the intent explicit and
  prevent compiler optimization issues.

How to fix:
- Change declaration to `volatile bool g_machine_alive = false;`

Risk: none.

---

### HACK-8: Duplicate #include in usb.c
**File**: `drivers/usb.c` lines 6 and 8
**Category**: copy-paste artifact

What was done:
- `#include <queue.h>` appears twice in the include block.

How to fix:
- Remove one copy.

Risk: none.

---

### HACK-9: Power declaration of 500mA in configuration descriptor
**File**: `port/tinyusb/usb_descriptors.c`
**Category**: inherited example template value

What was done:
- `TUD_CONFIG_DESCRIPTOR(1, ITF_NUM_TOTAL, 0, CONFIG_TOTAL_LEN, 0x00, 500)` declares 500mA as the
  maximum bus power draw. This was copied from a TinyUSB example template.

Why it is a hack:
- A USB HID device drawing 500mA is unusual and some hosts will flag it. Realistic draw for this
  device (RP2040/2350 + HID only, no motors or heavy peripherals on USB power) is well under 200mA.
- Advertising 500mA may prevent enumeration on hosts with strict power budgeting (e.g., powered
  USB hubs with per-port current limits).

How to fix:
- Change to a realistic value, e.g. 200 (200mA) or 100 (100mA).
- Note: attribute byte `0x00` means bus-powered, no remote wakeup. If remote wakeup is ever wanted,
  bit 5 of the attribute byte must also be set.

Risk: low — change only affects what the descriptor advertises, not actual current draw.

---

### Summary Table

| # | Issue | File(s) | Impact | Effort |
|---|---|---|---|---|
| HACK-1 | ~~OPT_OS_NONE polling~~ | — | — | **CLOSED** — OPT_OS_PICO is correct |
| HACK-2 | Dead usb_hid_periodic() template code | usb.c, usb.h | Low — confusion, dead code | Trivial |
| HACK-3 | Commented-out old API call | usb.c | Cosmetic | Trivial |
| HACK-4 | No readiness check on generic HID IN send | main.cc | Medium — silent packet loss | Low |
| HACK-5 | Silent drop in tud_hid_set_report_cb | usb.c | Medium — unobservable failure | Low |
| HACK-6 | Uninitialized padding bytes sent in HID report | main.cc | Low/medium — stack leak | Trivial |
| HACK-7 | g_machine_alive not volatile | main.cc | Low-medium — concurrency risk | Trivial |
| HACK-8 | Duplicate #include | usb.c | Cosmetic | Trivial |
| HACK-9 | 500mA power declaration | usb_descriptors.c | Low — descriptor inaccuracy | Trivial |

Recommended cleanup order:
1. HACK-2, 3, 6, 7, 8, 9 — all trivial; do in one pass before any other USB work.
2. HACK-4 and HACK-5 — add readiness guard and drop counter; do before testing USB stability.
3. HACK-1 — CLOSED. OPT_OS_PICO is the correct SDK default for RP2040/RP2350 + FreeRTOS.
   Switching to OPT_OS_FREERTOS caused regressions. No action required.

---

## 11. Active Debug Session Log (2026-04-20)

This section records the specific bugs found, root causes diagnosed, and fixes applied during the
first active debugging session after project reactivation. Intended as a reference for future work.

---

### 11.1 INI MAX_LINEAR_VELOCITY Mismatch (Scale Bug)

**Symptom**: LinuxCNC AXIS showed 60 IPM at 100% but the HMI maxvel ring showed the 4th LED (~25%).

**Root cause**: `hmi_sim.ini` had `[TRAJ] MAX_LINEAR_VELOCITY = 4` while all axis `MAX_VELOCITY`
entries were 1.0 unit/sec. `hmi.py` reads `[TRAJ] MAX_LINEAR_VELOCITY` at startup into
`configured_maxvel`. Because `configured_maxvel = 4.0` but actual ceiling was 1.0:

    OUT packet: int(round(1.0 * 14.0 / 4.0)) = 3  →  LED 3 (not 14)

The previous fix attempt had changed the wrong instance — there were two `MAX_LINEAR_VELOCITY` lines
(one in `[DISPLAY]` or similar, one in `[TRAJ]`). The `[TRAJ]` entry was still `= 4`.

**Fix**: Changed `[TRAJ] MAX_LINEAR_VELOCITY = 4` → `= 1` in `hmi_sim.ini`.

**Lesson**: When `hmi.py` and LinuxCNC disagree on the machine velocity ceiling, all three overrides
will display with wrong scale. Always verify the `[TRAJ]` section specifically; other INI sections
may also have `MAX_LINEAR_VELOCITY` entries that are not read by `hmi.py`.

---

### 11.2 Encoder Divisor Regression (4 Steps per Detent)

**Symptom**: Each physical detent of the override knobs jumped the value by 4 instead of 1.

**Root cause**: During a previous experimental session, `set_limits(1/2/3, 0, 14, 1)` had been
set with `div=1`. The physical encoders produce 4 quadrature counts per detent. With `div=1` the
internal counter and logical value are the same, so each detent incremented the logical value by 4.

**Encoder divisor mechanics** (`drivers/encoder.cc`):
- `set_limits(num, min, max, div)` stores internal limits as `min*div` and `max*div`.
- `value(num)` returns `m_cur_values[num] / div`.
- With `div=4`, 4 raw counts → 1 logical step. With `div=1`, 4 raw counts → 4 logical steps.

**Fix**: Restored `set_limits(1, 0, 14, 4)`, `set_limits(2, 0, 14, 4)`, `set_limits(3, 0, 14, 4)`
in `task_encoder.cc`.

**Compatibility note**: `set_encoder_value(enc, val)` (used for startup sync) calls `set_value()`
which stores `val * divisor` internally, so it remains correct with `div=4`.

---

### 11.3 USB Disconnect: LEDs and Display Not Reset

**Symptom**: When USB disconnected, the rings/LEDs held their last state instead of going dark,
and the display held the last encoder/key text instead of returning to the scrolling banner.

**Fix**: On the transition to "not alive" (`!leds_cleared`), in addition to clearing all LEDs,
a `DISPLAY_CMD_RESET` command is now sent to the display task:
- Added `DISPLAY_CMD_RESET` to `TaskDisplay::cmds` enum in `task_display.hh`.
- Handler in `task_display.cc::gui_task` restores `LV_LABEL_LONG_SCROLL_CIRCULAR` and resets
  label text to the boot banner string.
- Encoder/key update handlers now also set `LV_LABEL_LONG_CLIP` before updating text (previously
  the label stayed in scroll mode when the first encoder event arrived, which looked odd).
- `main.cc` disconnect handler sends the `DISPLAY_CMD_RESET` message under `#ifdef ENABLE_DISPLAY`.

---

### 11.4 WS2812 Ring LED Blip / Wrong Color on Wrong Ring

This was the most complex bug in the session. Multiple root causes were investigated.

#### 11.4.1 Batching Fix (Partial Improvement)

**Symptom**: When all three rings updated together (e.g. `machine_state_changed`), three separate
`update()` calls with intermediate states briefly visible.

**Root cause**: Each `set_ring_led(..., update_now=true)` triggered a full 45-pixel frame write.
Three sequential writes meant ring 0 could be seen with rings 1/2 still showing old state.

**Fix**: Added `LED_CMD_FLUSH` to `TaskLED::cmds`. All three ring commands now use
`update_now=false`, followed by a single `LED_CMD_FLUSH` queued after all three. The LED task
dequeues them in order: three buffer-only updates, then one `update()` call.

#### 11.4.2 WS2812 Frame Alignment (Root Cause)

**Symptom**: Magenta/cyan dots appearing briefly on the yellow ring (ring 0) when rapidly turning
knob 3 (ring 2). Knob 1 (ring 0) caused no artifacts on others. Pattern was asymmetric and
speed-dependent.

**Root cause diagnosis**: `pio_sm_put_blocking` is a **CPU-side busy-wait loop** on FIFO space:

    while (pio_sm_is_tx_fifo_full(pio, sm)) tight_loop_contents();
    pio->txf[sm] = value;

If FreeRTOS preempts the LED task (priority 2) mid-loop in favour of the encoder/matrix tasks
(priority 4), the CPU stops feeding the FIFO. The PIO runs independently and drains the remaining
FIFO entries (~4 × 30µs = 120µs max). Once the FIFO empties, the PIO **stalls** on
`out x, 1 side 0`, which holds the data pin **LOW**. If the stall exceeds ~50µs, the WS2812
strip latches the partial frame. When the LED task resumes, subsequent pixels are received by
the strip as a new frame starting from LED 0 — the remaining ring 2 pixels overwrite ring 0
and ring 1.

The asymmetry follows from send order: ring 0 is transmitted first, so it is most exposed to
preemption mid-frame when ring 2 knob turns arrive. Turning ring 0's knob never affects
others because rings 1/2 haven't started transmitting yet when preemption hits.

**Attempted fixes (did not fully resolve)**:
1. FIFO drain loop + `sleep_us(60)` after `update()` — 60µs was too short (OSR drain ~30µs
   + WS2812 reset >50µs = need 80µs+).
2. Increased to `sleep_us(100)` — still not robust; drain timing depends on where in the PIO
   cycle the FIFO check fires, and OSR overlap is not accounted for.
3. Absolute inter-frame timer (`busy_wait_until next_update_at`) — enforces minimum 1450µs
   between frame starts; correct but doesn't prevent mid-frame preemption.

**Actual fix**: `taskENTER_CRITICAL()` / `taskEXIT_CRITICAL()` wrapping the pixel write loop
in `ws2812.cc::update()`. This raises the interrupt priority mask, preventing FreeRTOS from
scheduling any task during the ~1.35ms pixel write. The CPU continuously feeds the FIFO with
no gaps, so the PIO never stalls.

```cpp
taskENTER_CRITICAL();
next_update_at = make_timeout_time_us(1450);
for (uint8_t i = 0; i < WS2812_NUM_LEDS; i++) {
    put_pixel(m_pio, m_sm, m_leds[i]);
}
taskEXIT_CRITICAL();
```

`busy_wait_until(next_update_at)` remains outside the critical section to avoid spinning with
preemption disabled longer than needed.

**Known limitation**: 1.35ms with preemption disabled is long for a FreeRTOS critical section.
At very high encoder spin speeds, encoder events could theoretically be missed during this window.
In practice, the encoder task (priority 4) queues events; it is the queue consumer (main_task)
that is delayed, not the event producer. No missed inputs observed in testing.

**Preferred future fix**: DMA transfer — see Section 12 (Pending Work).

---

### 11.5 Summary of Files Changed This Session

| File | Change |
|---|---|
| `linuxcnc/hmi_sim/hmi_sim.ini` | `[TRAJ] MAX_LINEAR_VELOCITY` corrected: `4` → `1` |
| `firmware/task_encoder.cc` | Encoder divisor restored: `div=1` → `div=4` for encoders 1-3 |
| `firmware/task_display.hh` | Added `DISPLAY_CMD_RESET` to `cmds` enum |
| `firmware/task_display.cc` | Handle `DISPLAY_CMD_RESET`; set `LONG_CLIP` before encoder/key text |
| `firmware/task_led.hh` | Added `LED_CMD_FLUSH` to `cmds` enum |
| `firmware/task_led.cc` | Handle `LED_CMD_FLUSH` → calls `m_rgbleds.update()` |
| `firmware/main.cc` | Send `DISPLAY_CMD_RESET` on disconnect; batch ring updates with single flush |
| `firmware/drivers/ws2812.cc` | Added `pico/time.h`, `FreeRTOS.h`, `task.h`; `update()` uses critical section + absolute inter-frame timer |

---

## 12. Pending Work

### 12.1 WS2812 DMA Refactor

The current `taskENTER_CRITICAL()` fix works but disables preemption for ~1.35ms. The correct
long-term fix is DMA:

- Allocate a 45-element `uint32_t` DMA buffer (pixels pre-shifted `<< 8` for PIO format).
- `dma_channel_configure()` with PIO TX FIFO as write address, `dreq = pio_get_dreq(pio, sm, true)`,
  32-bit transfers, read-increment.
- Fire with `dma_channel_start()` — CPU immediately free, PIO fed from DMA with no gaps.
- On next `update()`, wait for completion: `dma_channel_wait_for_finish_blocking()` or
  IRQ + semaphore for non-blocking.
- Keep `busy_wait_until(next_update_at)` for inter-frame gap enforcement.
- No critical section needed; fully preemption-safe.

### 12.2 hmi.py USB Reconnection

`hmi.py` has no reconnect loop. If the HMI USB device disconnects, the script will crash or hang.
Requirements for a safe implementation:
- Detect HID device loss via read/write exception.
- Poll `hid.enumerate()` until the device reappears; re-open when found.
- Do NOT call any LinuxCNC HAL/command APIs during the disconnected period (HAL pins hold last value).
- Do NOT restart LinuxCNC or the HAL component.
- On reconnect, force a full OUT packet re-sync to the HMI so all LEDs come up correct immediately.

---

## 13. Debug Session 2026-04-21 — HACK Cleanup + LED Disconnect Bugs

### 13.1 HACK Cleanup (HACK-2 through HACK-9)

All trivial and medium HACs from Section 10 were resolved in a single pass:

| HACK | Resolution |
|---|---|
| HACK-2 | Deleted `usb_hid_periodic()` from `usb.c` and its declaration from `usb.h` |
| HACK-3 | Removed stale `//tud_init(BOARD_TUD_RHPORT)` comment |
| HACK-4 | Wrapped `tud_hid_report(0,...)` in `tud_hid_n_ready(ITF_GENERIC_HID)` guard |
| HACK-5 | Added `volatile uint32_t usb_out_queue_drops`; logged per-heartbeat from `main_task` |
| HACK-6 | Added `bzero(&pkt, sizeof(pkt))` before IN packet field population |
| HACK-7 | `g_machine_alive` changed to `volatile bool` |
| HACK-8 | Removed duplicate `#include <queue.h>` |
| HACK-9 | USB config descriptor power changed `500` → `200` mA |

### 13.2 HACK-1: Closed as Not-a-Bug

Attempted to fix HACK-1 by setting `TINYUSB_OPT_OS OPT_OS_FREERTOS` in CMakeLists.txt. This caused
the HMI to fail to enter offline mode on hmi.py stop (all LEDs stuck, rings held last state).
Reverting to `OPT_OS_PICO` (the SDK default) restored correct behavior.

**Conclusion**: `OPT_OS_PICO` is correct for RP2040/RP2350 + FreeRTOS. The Pico SDK's `osal_pico.h`
uses `pico/sem.h` primitives that are FreeRTOS-interoperable via `configSUPPORT_PICO_SYNC_INTEROP=1`.
`OPT_OS_FREERTOS` is for bare FreeRTOS ports without the Pico SDK layer. HACK-1 is closed; the
broken `add_definitions(-DCFG_TUSB_OS=OPT_OS_FREEERTOS)` line (typo, harmless but confusing) was
removed. No replacement needed.

### 13.3 Homed State + Program Control Gating

- Added `homed` byte (byte 13) to OUT packet: `s.homed.count(1) == s.joints`.
- `hmi.py` gates start/pause/step buttons when `status['homed']` is false.
- Firmware slow-blinks STOP LED (LED10) at 1 s period when enabled but not homed.
- OUT packet is now 14 bytes total.

### 13.4 LED Disconnect Clear Bug (Queue Overflow)

**Symptom**: On hmi.py stop, LED rings held last state; M1 Stop and Coolant LEDs remained lit.

**Root cause 1 — Queue overflow**: The `leds_cleared` block in `main_task` sends 15+ LED commands
in a burst. The LED task `cmd_queue` was depth 10 → commands after the 10th (rings 1+2, LEDs 6+7)
were silently dropped by `xQueueSend(..., 0)`.
**Fix**: Raised LED task queue depth from 10 → 32 (`task_led.cc`).

**Root cause 2 — Missing I2C flush**: `set_simple_led(6, 0, NORMAL)` and `set_simple_led(7, 0, NORMAL)`
were queued without `now=true`. LED 7 (`now=false`) left both LEDs 6 and 7 in the I2C buffer with
no subsequent `now=true` call to flush them to hardware.
**Fix**: Changed `set_simple_led(7, 0, NORMAL)` → `set_simple_led(7, 0, NORMAL, true)`.

### 13.5 Files Changed This Session

| File | Change |
|---|---|
| `firmware/drivers/usb.c` | HACK-2,3,5,8; added `usb_out_queue_drops`; drop logged per-heartbeat |
| `firmware/drivers/usb.h` | HACK-2: removed `usb_hid_periodic` decl; added `extern usb_out_queue_drops` |
| `firmware/main.cc` | HACK-4,6,7; homed state vars; not-homed slow blink; LEDs 6+7 in disconnect clear; flush fix |
| `firmware/task_led.cc` | Queue depth 10 → 32 |
| `firmware/port/tinyusb/usb_descriptors.c` | HACK-9: 500 → 200 mA |
| `firmware/CMakeLists.txt` | Removed broken `add_definitions(-DCFG_TUSB_OS=OPT_OS_FREEERTOS)` |
| `linuxcnc/hmi.py` | homed byte; program control gating; coolant/opt_stop edge detection |

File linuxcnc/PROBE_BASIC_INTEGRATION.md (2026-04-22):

# Pico CNC HMI — Probe Basic Integration Guide

This guide describes how to add the Pico CNC HMI to an **existing Probe Basic machine
configuration**. It uses the template config at
`~/dev/probe_basic/configs/probe_basic/` as the reference starting point, which is what
most installations are based on.

> [!NOTE]
> All paths starting with `<your-config>/` refer to your machine's LinuxCNC config directory
> (e.g. `~/linuxcnc/configs/my_machine/`). Paths starting with `<hmi-repo>/` refer to the
> root of this repository (`pico-cnc-hmi/`).

---

## Step 1 — Install the Python dependency

The bridge script requires `python3-hid` (hidapi Python bindings):

```bash
sudo apt install python3-hid
# or, if running from a venv:
pip install hidapi
```

Verify:

```bash
python3 -c "import hid; print(hid.__version__)"
```

---

## Step 2 — USB permissions

The bridge runs as a normal user and needs read/write access to the HID device.
Create a udev rule so the device is accessible without `sudo`:

```bash
sudo tee /etc/udev/rules.d/99-pico-cnc-hmi.rules << 'EOF'
# Pico CNC HMI (TangentAudio, VID=0xCAFE PID=0x4008)
SUBSYSTEM=="hidraw", ATTRS{idVendor}=="cafe", ATTRS{idProduct}=="4008", \
    MODE="0660", GROUP="plugdev"
EOF
sudo udevadm control --reload-rules && sudo udevadm trigger
```

Add your user to the `plugdev` group if not already a member:

```bash
sudo usermod -aG plugdev $USER   # log out and back in afterwards
```

---

## Step 3 — Copy files to your config directory

Copy the following two files from `<hmi-repo>/linuxcnc/` into your config directory:

```
<hmi-repo>/linuxcnc/hmi.py                  →  <your-config>/hmi.py
<hmi-repo>/linuxcnc/pb_sim/hmi_wiring.hal   →  <your-config>/hmi_wiring.hal
```

> [!IMPORTANT]
> Use `pb_sim/hmi_wiring.hal` (not `hmi_sim/hmi_wiring.hal`).  The Probe Basic
> version loads both `not` RT module instances in a single `loadrt` call to avoid a
> conflict with `probe_basic_postgui.hal` on POSIX non-realtime kernels.  On a real
> RT kernel this is usually fine either way, but the merged call is safe in both cases.

---

## Step 4 — Create `hmi_bridge.hal`

Create `<your-config>/hmi_bridge.hal` with this content:

```hal
# Pico CNC HMI bridge — loads the Python userspace component.
loadusr -Wn hmi python3 /home/YOUR_USER/linuxcnc/configs/my_machine/hmi.py
```

Use the **absolute path** to `hmi.py` in your config directory.

---

## Step 5 — INI changes

Open your machine INI file and make the following additions.

### `[DISPLAY]` section

Add these keys. Adjust values to match your machine:

```ini
# --- Pico CNC HMI settings ---

# Maximum rapid override for the rapid-override knob ring.
# Must match or be <= what your machine can actually do.
MAX_RAPID_OVERRIDE = 1.0        # 1.0 = 100%

# Power-law exponent for the maxvel knob.
# > 1 concentrates resolution at the low end.  3.0 is a good starting point.
# Segment 7/14 (mid-ring) = (0.5 ** exponent) of the usable range.
# exponent=1 gives a linear mapping.
HMI_MAXVEL_CURVE = 3.0

# Minimum velocity at segment 1 of the maxvel knob, in the same units as
# [TRAJ] MAX_LINEAR_VELOCITY (inches/min or mm/min — NOT a fraction).
# Segment 0 is always 0 (machine stopped).
HMI_MAXVEL_MIN = 1.0
```

> [!NOTE]
> `MAX_FEED_OVERRIDE` and `MAX_LINEAR_VELOCITY` are already in most Probe Basic INIs.
> The HMI reads them automatically — no change needed for those.

### `[HAL]` section

Add the two new HALFILE entries **before** `HALUI` and `POSTGUI_HALFILE`:

```ini
[HAL]
HALFILE = hallib/core_sim.hal           # your existing machine HAL (name varies)
# ... other existing HALFILE entries ...

# --- Add these two lines ---
HALFILE = hmi_bridge.hal                # starts the Python HMI bridge
HALFILE = hmi_wiring.hal                # wires HMI pins to motion/jog/halui

HALUI = halui
POSTGUI_HALFILE = probe_basic_postgui.hal
TWOPASS = on
```

> [!IMPORTANT]
> `hmi_bridge.hal` must come **before** `hmi_wiring.hal` since the wiring file
> references HAL pins that the bridge creates.  Both must come before `POSTGUI_HALFILE`.

---

## Step 6 — Modify `probe_basic_postgui.hal`

The stock postgui does `loadrt not` to create a `not` gate for the cycle timer.
`hmi_wiring.hal` also loads the `not` module (as `hmi-not`).  On POSIX non-realtime
kernels **you cannot `loadrt` the same module twice**, even with different instance names.

Make the following three-line change in your `probe_basic_postgui.hal`:

```diff
-loadrt not
+loadrt not names=pb-not

-addf not.0 servo-thread
+addf pb-not servo-thread

-net prog-running not.0.in <= halui.program.is-idle
-net cycle-timer time.0.start <= not.0.out
+net prog-running pb-not.in <= halui.program.is-idle
+net cycle-timer time.0.start <= pb-not.out
```

Everything else in the postgui file stays the same.

> [!NOTE]
> On a real realtime kernel (`RTAI`, `Xenomai`, or `PREEMPT_RT`) this conflict usually
> does not occur because kernel modules are shareable objects.  The rename is still
> recommended so your config works in simulation mode too.

---

## Step 7 — `halui.home-all` wiring

`hmi_wiring.hal` already includes:

```hal
net hmi-home-all hmi.home-all => halui.home-all
```

This is what makes the **STOP + CYCLE START chord** (see below) trigger Probe Basic's
REF ALL home sequence.  No additional action is needed here — it is already in the file
you copied in Step 3.

---

## Step 8 — Adapt `hmi_wiring.hal` for your axis count

The provided file is written for a **3-axis XYZ machine**.  If your machine has more
joints (e.g. XYZAC — 5 joints), extend the file as follows:

1. **`demux personality`** — change `personality=4` to `personality=<N+1>` where N is
   your total joint count (+1 for the "no axis" state at index 0).

2. **`and2` instances** — add one `hmi-and-shuttle-<axis>` and one `hmi-and-jog-<axis>`
   for each additional axis:
   ```hal
   loadrt and2 names=hmi-and-shuttle-x,...,hmi-and-shuttle-a,hmi-and-jog-x,...,hmi-and-jog-a
   ```

3. **`addf` lines** — add `addf` for each new `and2` instance.

4. **`net` lines** — for each additional axis wire:
   ```hal
   net sel-shuttle-axis-a hmi-and-shuttle-a.out => halui.joint.3.plus halui.axis.a.plus
   net sel-jog-axis-a     hmi-and-jog-a.out     => axis.a.jog-enable joint.3.jog-enable
   net hmi.jog-increment  => axis.a.jog-scale joint.3.jog-scale
   ```
   Also add `setp halui.joint.3.minus 0` (and `.axis.a.minus 0`) to prevent runaway jog.

5. **Demux output** — wire the new demux output to both shuttle and jog and2 inputs:
   ```hal
   net aa-in1 hmi-and-shuttle-a.in1 <= hmi-axis.demux.out-04 => hmi-and-jog-a.in1
   ```

---

## INI key reference

| Key | Section | Default | Description |
|---|---|---|---|
| `MAX_LINEAR_VELOCITY` | `[TRAJ]` | — | Upper end of maxvel knob range (required) |
| `MAX_FEED_OVERRIDE` | `[DISPLAY]` | — | Upper end of feed-override knob (required) |
| `MAX_RAPID_OVERRIDE` | `[DISPLAY]` | 1.0 | Upper end of rapid-override knob |
| `HMI_MAXVEL_CURVE` | `[DISPLAY]` | 2.0 | Power-law exponent (1 = linear, 3 = aggressive low-end) |
| `HMI_MAXVEL_MIN` | `[DISPLAY]` | 0.0 | Min velocity at segment 1 (same units as MAX_LINEAR_VELOCITY) |

---

## HAL pin reference

All pins are on the `hmi` component, created by `hmi.py`.

| Pin | Type | Dir | Description |
|---|---|---|---|
| `hmi.jog.axis` | U32 | OUT | Selected axis (0=none, 1=X, 2=Y, 3=Z, …) |
| `hmi.jog.step` | FLOAT | OUT | Jog increment (inches or mm) |
| `hmi.jog.inner.value` | S32 | OUT | Incremental jog encoder counts |
| `hmi.jog.outer.value` | FLOAT | OUT | Shuttle ring velocity (units/s; 0 when centered) |
| `hmi.jog.is-shuttling` | BIT | OUT | TRUE while shuttle ring is displaced |
| `hmi.home-all` | BIT | OUT | Pulsed TRUE for one cycle when STOP+START chord fires |
| `hmi.knob.0.value` | U32 | OUT | Feed-override ring segment (0–14) |
| `hmi.knob.1.value` | U32 | OUT | Rapid-override ring segment (0–14) |
| `hmi.knob.2.value` | U32 | OUT | Maxvel ring segment (0–14) |

---

## STOP + CYCLE START chord (Home All Axes)

When the machine is **powered, out of e-stop, and not yet homed**:

1. Press and hold **STOP**
2. While holding STOP, press and hold **CYCLE START**
3. Hold both for **2 seconds**

**Firmware feedback during countdown:** STOP LED fast-blinks (4 Hz).  Releasing either
button before 2 seconds cancels the chord.

**On fire:** both STOP and RUN LEDs flash full brightness; `hmi.home-all` is pulsed to
`halui.home-all`; `c.home(-1)` is also called directly.  The machine begins homing all
joints simultaneously.

**Guard:** the chord is silently ignored if the machine is in e-stop, not enabled, or
already homed.  Once homed, STOP and CYCLE START return to their normal functions.

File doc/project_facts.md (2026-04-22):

- Project: Pico 2 CNC HMI firmware + LinuxCNC host bridge.
- Maturity: early bring-up/debug/POC; dormant ~1 year as of 2026-04-20.
- Host bridge: ../linuxcnc/hmi.py (python-hid + linuxcnc stat/command + HAL pins).
- HID: vendor 0xCAFE, dual interface (generic in/out + keyboard).
- Host heartbeat increments every 500 ms in hmi.py.
- Encoder scaling in host: knob values interpreted as 0..14 for feed/rapid/maxvel overrides.
- Outstanding risks: encoder set_value scaling logic in firmware, USB task assert check, LED task tight loop.
- Confirmed decisions (2026-04-20): MODE_AUTO and MODE_TELEOP share motion behavior for now; no header validation yet; no stricter HID filtering yet; LED task changes deferred; display remains bring-up-only with scope TBD.
- Design guidance preference: treat current implementations as provisional in early stage; include improvement suggestions and redesign options rather than assuming present structure is fixed.
- Physical layout (in-progress): device roughly 101-key keyboard size; monochrome display; some single-color key LEDs; rotary knobs with RGB rings.
- Section A: 4x5 keys, lower-right has one horizontal 2u key; intended future G-code/MDI area; labels/functions TBD.
- Section B: 4x5 keys, lower-right has one vertical 2u key; intended numeric/operator + prev/next + enter area aligned with current key map.
- Section C: to right of B with larger gap; 5 rows machine-control keys: top row M1 Stop + Coolant (both LED status, implemented), then Single Step (LED, implemented), Pause (LED, implemented), Stop (LED, implemented), Cycle Start (LED, implemented).
- Section C key codes: M1 Stop=0x3d/LED6, Coolant=0x3e/LED7, Step=0x33/LED8, Pause=0x34/LED9, Stop=0x35/LED10, Cycle Start=0x36/LED11.
- Section D: to right of C with small gap; 3 vertical continuous rotary encoders, each with RGB ring (near-360 with bottom wedge gap), conceptual 0-100% with wedge marking discontinuity.
- Section E (rightmost/final): display at top; below is LED-backed key grid.
- Section E key rows: top row jog increment select (0.010 in, 0.001 in, 0.0001 in); next row axis select (X/Y/Z).
- Section E jog control: concentric jog/shuttle knob; outer ring spring-centers for continuous variable jogging; inner ring is incremental encoder wheel; both act on selected axis.
- Operator flow map (working): Manual jog flow via Section E (increment+axis+concentric jog), program control flow via Section C motion keys, override tuning flow via Section D encoders, keyboard/MDI hybrid via Sections B/A (A still TBD), display flow currently diagnostics-only.
- LED/state snapshot captured in summary: manual-mode increment/axis LEDs use indices 0-5, interp presentation uses LEDs 8-11, encoder rings 0-2 map to knobs 1-3 with fixed colors; all cleared when machine link not alive.
- Documentation preference: refer to controls by physical function names (e.g., Cycle Start, Axis X) alongside matrix code, not by LED index alone.
- Deployment model: HMI is not standalone; always paired with LinuxCNC touchscreen GUI.
- Primary GUI targets: Probe Basic (QtPyVCP) and custom QtVCP derived from QtDragon.
- Product goal: HMI + touchscreen should replace keyboard/mouse for ~95% of use; likely exception is complex G-code editing.
- 2026 SDK audit: project baseline is pico-sdk 2.1.1 (TinyUSB 0.18.0). Upstream has moved to pico-sdk 2.2.0 and newer TinyUSB releases; recommend branch-based SDK bump trial, USB robustness instrumentation, and FreeRTOS import freshness check before larger refactors.

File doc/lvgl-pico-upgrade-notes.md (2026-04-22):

# LVGL + Pico SDK Upgrade Notes (firmware/)

## SDK 2.1.1 → 2.2.0
- New module `pico_platform_common` added in 2.2.0
- Must add to LVGL include paths in CMakeLists.txt:
  `${PICO_SDK_PATH}/src/rp2_common/pico_platform_common/include/`

## LVGL 9.3.0 → 9.5.0
- `lv_conf.h` discovery changed — use `set(LV_BUILD_CONF_DIR <dir> CACHE PATH "" FORCE)` before `add_subdirectory(lvgl)`
- NXP VGLite backend removed — requires clean build wipe after LVGL version change (stale glob)
- `lvgl/env_support/cmake/custom.cmake` must exist as an empty file (user hook); create it with `touch`, then re-run cmake and `touch build/build.ninja` to fix timestamps
- cmake re-run loop root cause: custom.cmake listed as phony output but missing → ninja always dirty

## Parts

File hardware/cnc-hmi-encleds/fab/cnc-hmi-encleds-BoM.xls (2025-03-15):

Comment | Designator | Qty | Footprint | LCSC Part Number
0.1uF 16v | C1,C2 | 2 | 603 | C1590
1uF 16v | C3 | 1 | 805 | C1712
WS2812B-2020 | D1,D2,D3,D4,D5,D6,D7,D8,D9,D10,D11,D12,D13,D14,D15,D16,D17,D18,D19,D20,D21,D22,D23,D24,D25,D26,D27,D28,D29,D30,D31,D32,D33,D34,D35,D36,D37,D38,D39,D40,D41,D42,D43,D44,D45 | 45 | LED_WS2812B-2020_PLCC4_2.0x2.0mm | C965555
SN74LVC1T45DBV | U1 | 1 | SOT-23-6 | C7843

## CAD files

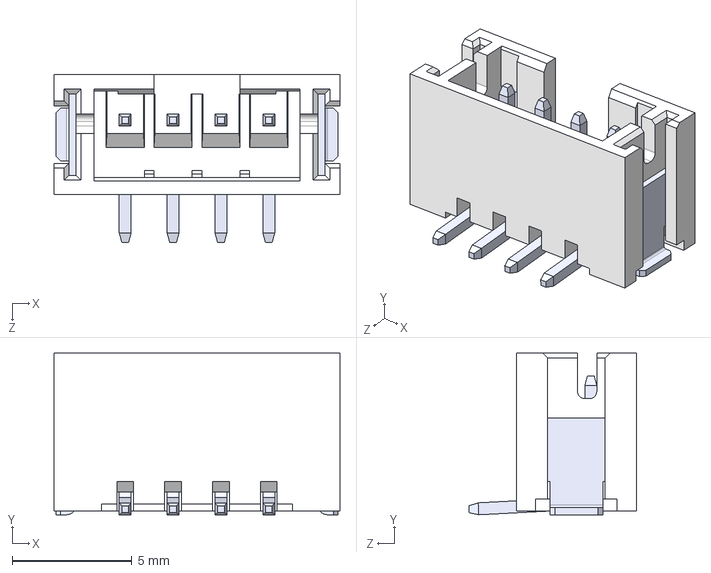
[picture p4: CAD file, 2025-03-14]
hardware/cnc-hmi-encleds/3D/B4B-PH-SM4-TBT.step
12.0 x 6.75 x 7.00 mm

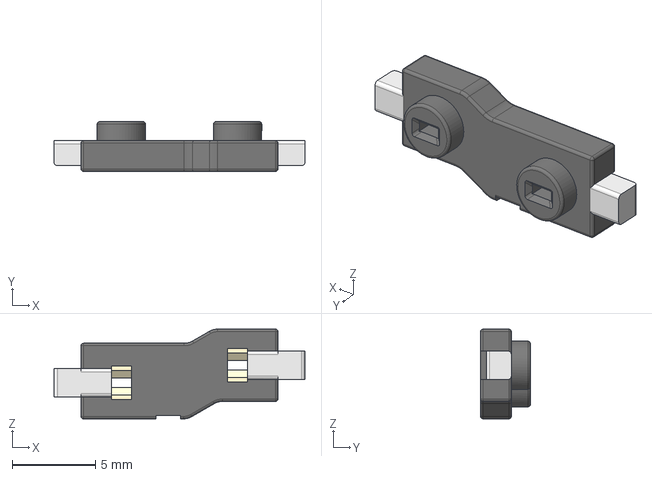
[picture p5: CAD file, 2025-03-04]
hardware/cnc-hmi/MX_V2-main/3D/Gateron-KS33-Socket.step
15.1 x 3.00 x 5.40 mm

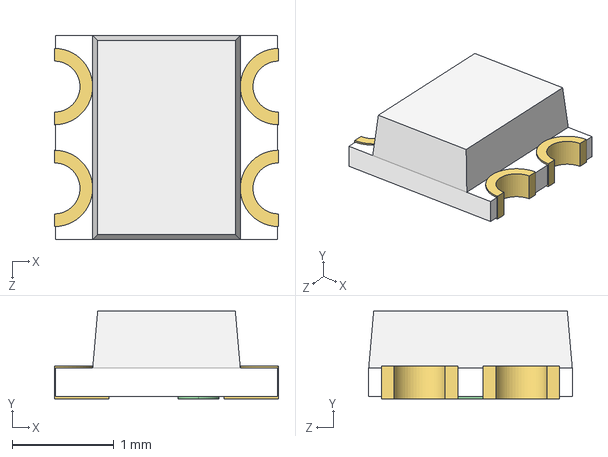
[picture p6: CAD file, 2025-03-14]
hardware/cnc-hmi-encleds/3D/WS2812-2020.STEP
2.20 x 0.86 x 2.00 mm

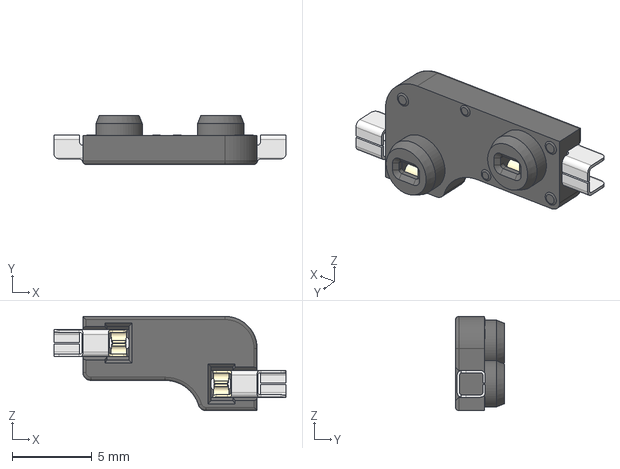
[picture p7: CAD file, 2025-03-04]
hardware/cnc-hmi/MX_V2-main/3D/MX-Hotswap-Socket.step
14.5 x 3.05 x 5.89 mm

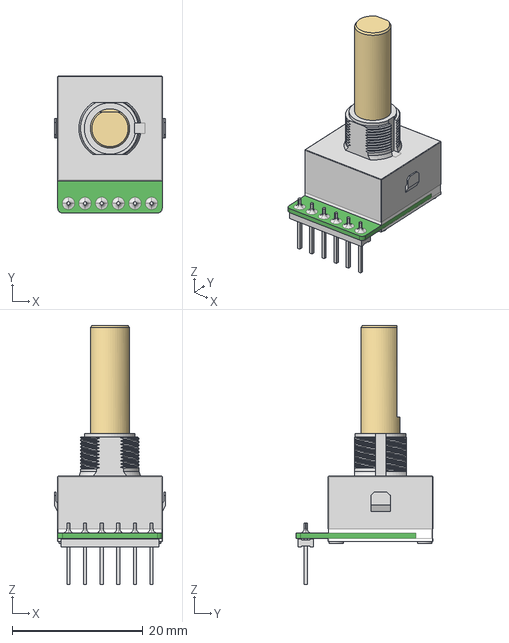
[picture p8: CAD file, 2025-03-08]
hardware/cnc-hmi/3D/REC16K25-201.stp
17.0 x 20.9 x 39.6 mm

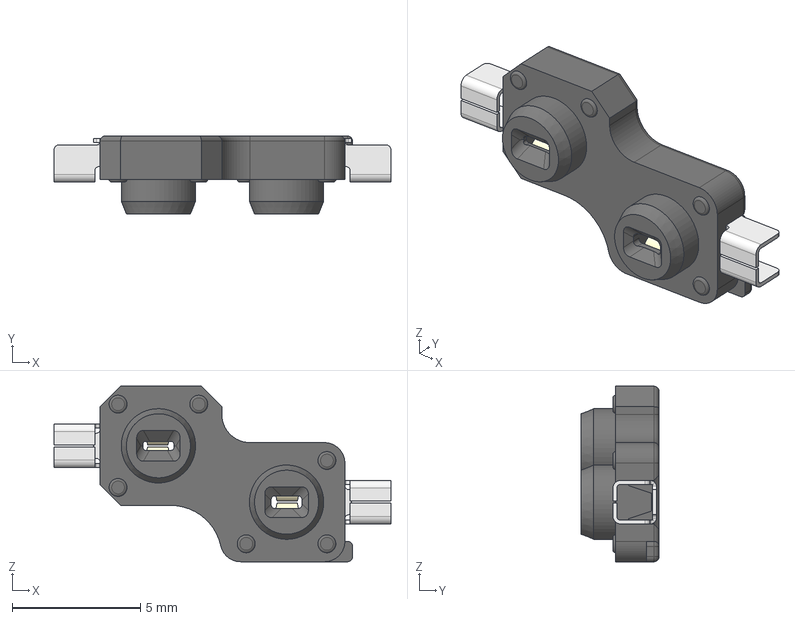
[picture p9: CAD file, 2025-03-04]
hardware/cnc-hmi/MX_V2-main/3D/Kailh-Choc-Socket-CPG135001S30.step
13.1 x 3.05 x 6.85 mm
Insert 2
Insert 1

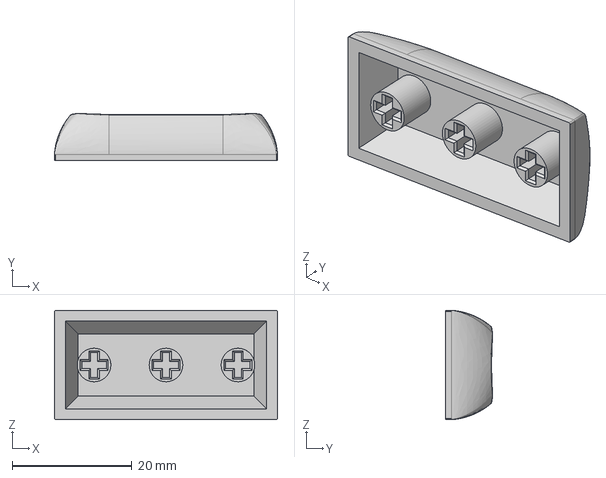
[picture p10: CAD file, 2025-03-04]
hardware/cnc-hmi/3D/DSA 2u.step
37.2 x 7.91 x 18.2 mm

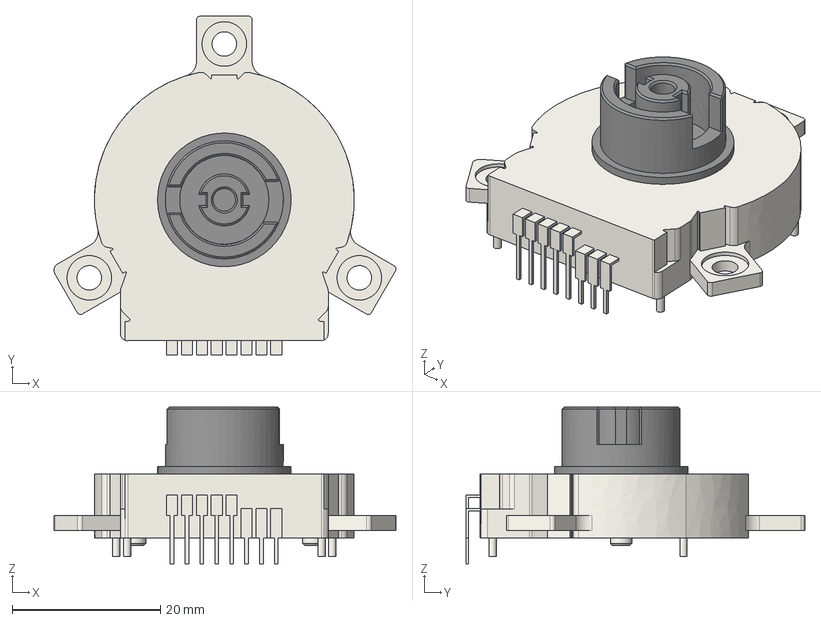
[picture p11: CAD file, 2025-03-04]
hardware/cnc-hmi/3D/SRGPHJ3200 v9.step
46.1 x 45.6 x 21.1 mm
Shafts

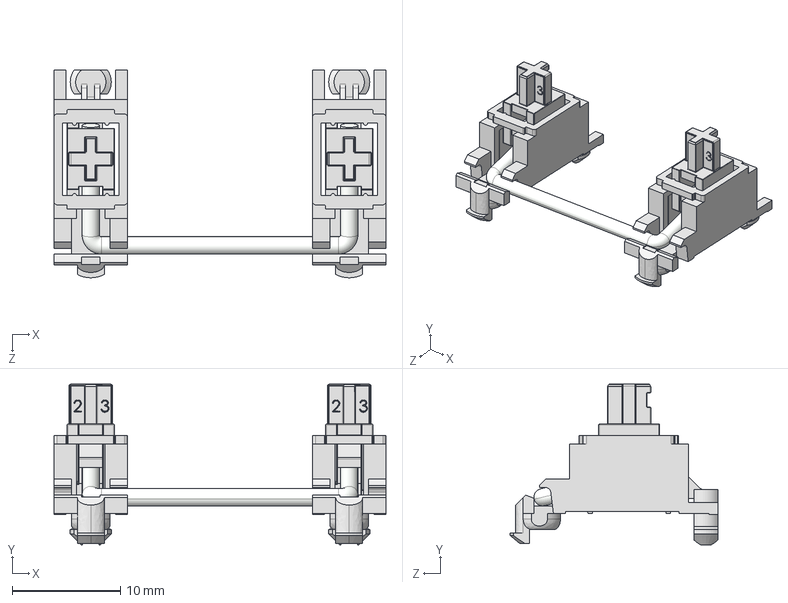
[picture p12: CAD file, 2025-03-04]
hardware/cnc-hmi/3D/Stabilizer-2u.STEP
30.7 x 14.9 x 19.2 mm
mx Stabilizer base 16828 x 2
mx Stabilizer key 16828 x 2
metal stick 16828

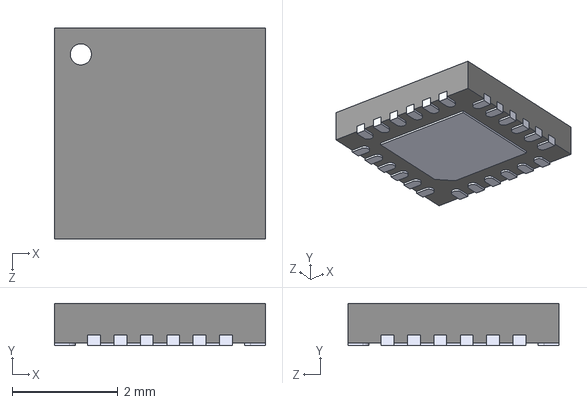
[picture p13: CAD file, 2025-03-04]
hardware/cnc-hmi/3D/TCA8418RTWR.step
4.00 x 0.8 x 4.00 mm

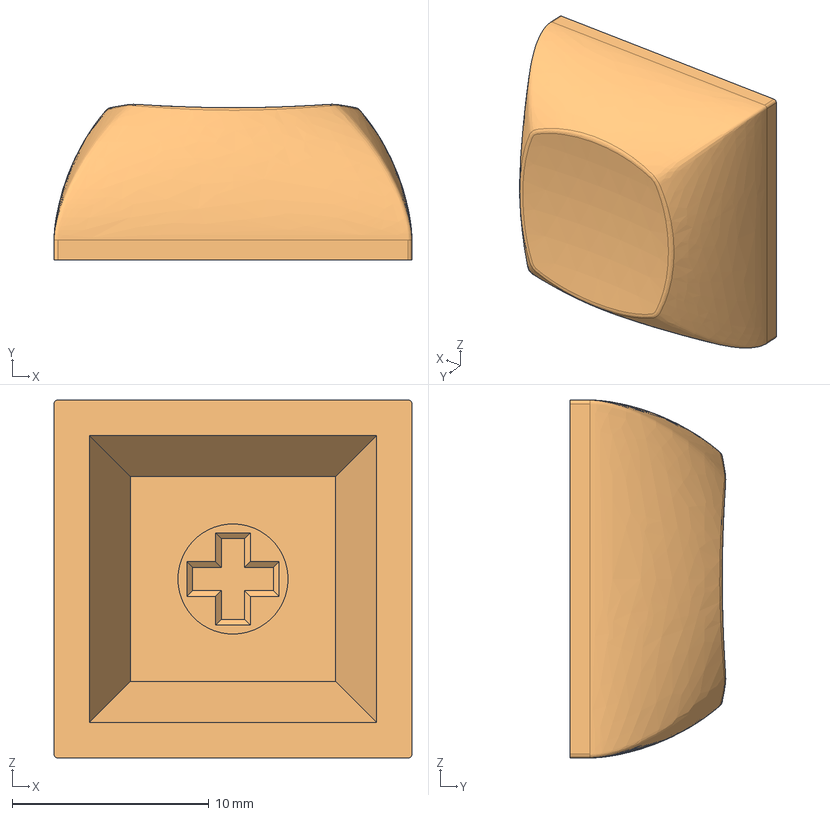
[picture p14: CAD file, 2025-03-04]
hardware/cnc-hmi/3D/DSA 1u.step
18.2 x 7.91 x 18.2 mm

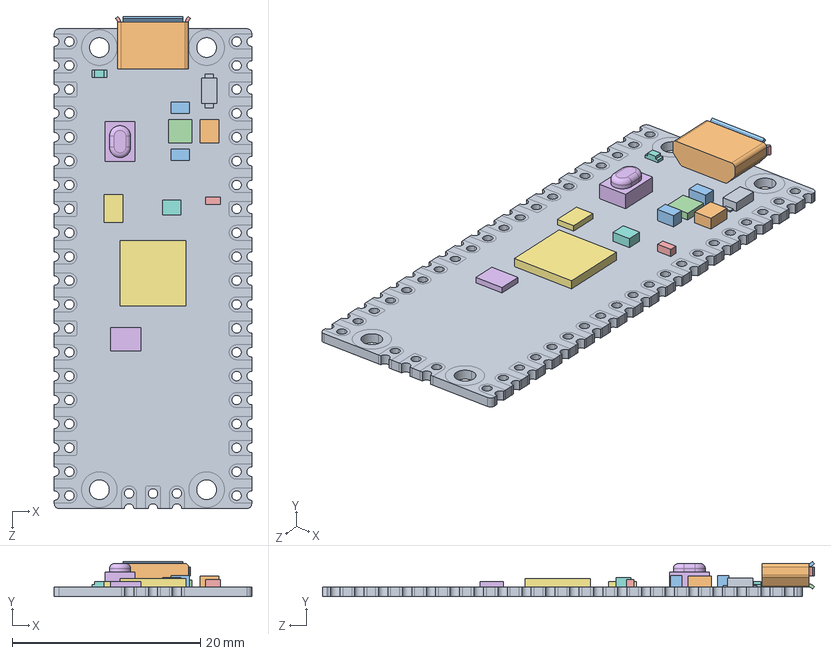
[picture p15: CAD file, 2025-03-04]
hardware/cnc-hmi/3D/RP-006426-DD-A-Raspberry Pi Pico 2 3D CAD Model R5 24 07 24.step
21.0 x 3.73 x 52.3 mm
PICO_REF_BOARD
PICO_REF_USB
PICO_REF_SWITCH
PICO_REF_MICROCONTROLLER
PICO_REF_LED
PICO_REF_COMP_1
PICO_REF_COMP_2
PICO_REF_COMP_3 x 2
PICO_REF_COMP_4
PICO_REF_COMP_5
PICO_REF_COMP_6
PICO_REF_COMP_7
PICO_REF_INDUCTOR

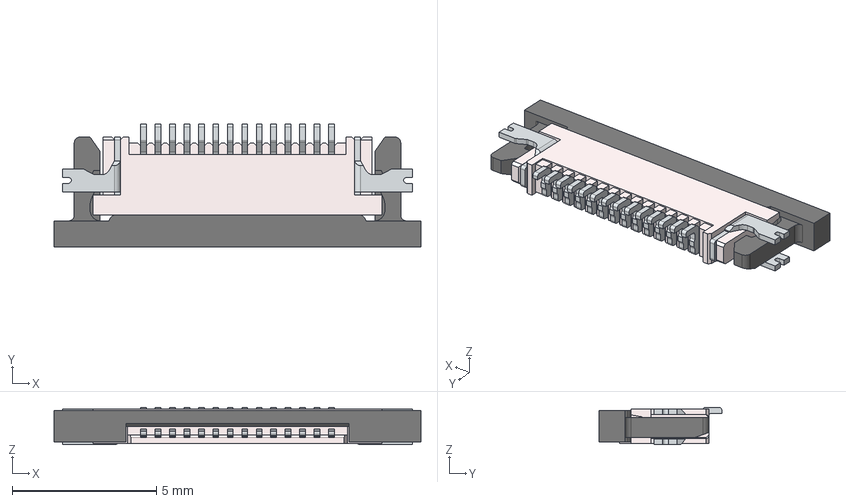
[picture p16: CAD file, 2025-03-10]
hardware/cnc-hmi/3D/687114183622_Download_STP_687114183622_rev1.stp
12.7 x 4.25 x 1.29 mm
68x114183x22
68x114183x22_Actuator
68X1xx183x22_Solder_Pad2
68X1XX183X22_Solder_Pad
68X1XX183X22_Pin_TOP x 14

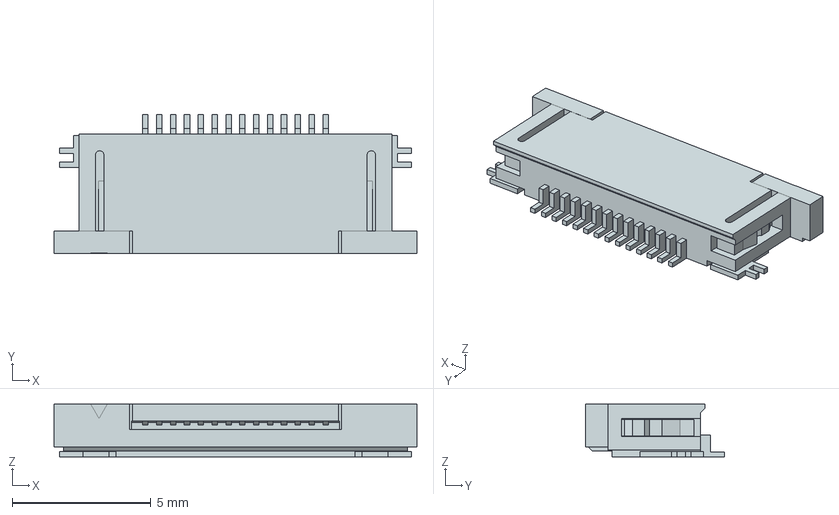
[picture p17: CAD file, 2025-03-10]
hardware/cnc-hmi/3D/527451496.stp
13.1 x 5.00 x 1.91 mm

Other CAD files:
hardware/cnc-hmi/3D/TLC59116FIPWR.step

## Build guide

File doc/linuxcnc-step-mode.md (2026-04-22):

# LinuxCNC single-step mode discrimination

## Key finding
`task_paused=1` appears in BOTH step mode AND normal AUTO_PAUSE.
The correct discriminator is `exec_state`:

| Scenario | task_paused | exec_state | in_step_mode() |
|---|---|---|---|
| Step mode, non-motion step waiting | 1 | 2 (EXEC_DONE) | True |
| Step mode, after motion step waiting | 1 | 5 (EXEC_WAITING_FOR_IO) | True |
| Normal run AUTO_PAUSE | 1 | 7 (EXEC_WAITING_FOR_MOTION_AND_IO) | False |
| Normal run / idle | 0 | any | False |

## in_step_mode() implementation
```python
def in_step_mode() -> bool:
    if not status['task_paused']:
        return False
    return status['exec_state'] != linuxcnc.EXEC_WAITING_FOR_MOTION_AND_IO
```

## interp_state constants on LinuxCNC 2.9.8
INTERP_IDLE=1, INTERP_READING=2, INTERP_PAUSED=3, INTERP_WAITING=4 (sequential, NOT power-of-2)

## OUT packet layout (hmi.py → firmware)
Byte 0: 0xaa header
Byte 1: heartbeat
Byte 2: estop
Byte 3: enabled
Byte 4: mode
Byte 5: interp_state (mapped sequential)
Byte 6: feedrate_override (0-14 segments)
Byte 7: rapidrate_override (0-14 segments)
Byte 8: maxvel_override (0-14 segments)
Byte 9: in_step_mode() (0/1)
Byte 10: inpos (0/1)
Byte 11: optional_stop (0/1)
Byte 12: coolant/flood (0/1)
Total: 13 structured bytes + pad to 64. Format string: '<BBBBBBBBBBBBB'

## Single-step LED behaviour (firmware)
- PAUSED/WAITING + task_paused=1, inpos=True  → step(8)+run(11) BLINK (waiting for Cycle Start)
- PAUSED/WAITING + task_paused=1, inpos=False → step(8)+run(11) SOLID (machine moving)
- READING + task_paused=1                      → step(8)+run(11) SOLID (executing)
- PAUSED + task_paused=0                       → pause(9) BLINK (normal AUTO_PAUSE)
- READING/WAITING + task_paused=0              → run(11) SOLID (normal run)
- IDLE                                          → stop(10) SOLID

## Button gating (hmi.py)
- CYCLE START from step PAUSED/WAITING → AUTO_STEP
- CYCLE START from normal PAUSED → AUTO_RESUME
- CYCLE START from IDLE → AUTO_RUN
- STEP from IDLE only → enters step mode via AUTO_STEP
- PAUSE only fires when READING/WAITING and not in_step_mode()
- STOP always aborts

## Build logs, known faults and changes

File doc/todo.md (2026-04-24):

# Pending Work

## WS2812 DMA refactor (LED task)
Current fix: `taskENTER_CRITICAL()` wraps the 45-pixel `put_pixel` loop in `ws2812.cc::update()`.
This works but holds preemption disabled for ~1.35ms (45 pixels × 30µs at 800kHz).

**Why the fix was needed:**
- `pio_sm_put_blocking` is a CPU-side busy-wait on FIFO space, not a DMA transfer
- If FreeRTOS preempts the LED task mid-loop (encoder/matrix tasks run at priority 4 vs LED at 2),
  the CPU stops feeding the FIFO
- The PIO keeps running independently and drains the remaining FIFO entries (~120µs for 4 deep)
- Once FIFO empty, PIO stalls on `out x, 1 side 0` which holds the data pin **LOW**
- >50µs of LOW = WS2812 reset/latch — strip latches the partial frame at whatever pixel it reached
- Next pixels after resume land shifted — cyan/magenta appear on the yellow ring etc.
- The effect was asymmetric: turning knob 3 (ring 2, sent last) corrupted rings 0 and 1
  because those were still in-flight when preemption hit; knob 1 (ring 0, sent first)
  never affected the others because rings 1 and 2 were not yet started

**Preferred long-term fix: DMA**
- Allocate a 45-element uint32 buffer (shifted left 8 for PIO format, same as `put_pixel`)
- Use `dma_channel_configure()` with the PIO TX FIFO as the write address,
  dreq = `pio_get_dreq(pio, sm, true)`, 32-bit transfers, read-increment
- Fire with `dma_channel_start()` — CPU immediately free, PIO fed from DMA with no gaps
- On next `update()` call, wait for DMA completion before re-arming:
  `dma_channel_wait_for_finish_blocking()` (or use an IRQ + semaphore for non-blocking)
- Still need the inter-frame gap (>50µs after last pixel) — track with `make_timeout_time_us`
  same as current `next_update_at` logic
- No critical section needed; fully preemption-safe

## COMPLETED

### Display overlay system refactor + LVGL deadlock fix (2026-04-24)
Replaced single shared overlay panel with four dedicated panels (jog, knob, select,
bootsel), each with pre-configured fonts and layout. Jog overlay uses dirty-flag
coalescing (Option A from the original plan below) — `publish_jog_overlay()` writes to a
shared struct; `gui_task` polls it with 50ms render throttling. Knob overlay change-gates
`transient_until` so encoder settling can't keep the overlay stuck.

**Typography:** JetBrains Mono SemiBold 48px (4bpp) for overlay letter+value, 20px (4bpp)
for status row overrides. Dim gray (0x60) axis/mode identifier, bright white value.

**Root cause of persistent gui_task freeze:** LVGL 9's `LV_USE_OS = LV_OS_FREERTOS` created
an internal draw thread with its own stack and mutexes. Under heavy event pressure
(simultaneous jog + knob encoder input), the draw thread deadlocked — gui_task blocked
forever waiting for render completion. No LVGL assertion fired because the hang was in a
FreeRTOS semaphore wait, not an LVGL code path. Fix: `LV_USE_OS = LV_OS_NONE` — all LVGL
calls are single-threaded (gui_task only), so the internal threading was unnecessary.

Also updated `LV_ASSERT_HANDLER` to print file:line before halting (was silent `while(1)`).

### USB BOOTSEL reboot + firmware updater (2026-04-24)
Magic command byte `cmd=0xB0` in OUT packet offset 14 triggers `reset_usb_boot(0, 0)`.
`linuxcnc/update_firmware.py` automates the full cycle: BOOTSEL reboot → wait for
RP2350/RPI-RP2 mass storage mount → copy .uf2 → wait for device to come back online.
Display shows "USB Boot" message before reset (display clears when bootloader resets GPIOs).

### Step-mode LED and step stacking: velocity-based signals (2026-04-24)
Replaced `inpos`-based logic with `s.current_vel` for both the LED blink/solid indicator
and the step stacking guard. `inpos` stays False after mid-motion PAUSE; `s.paused` stays
True throughout step execution. `current_vel` reliably transitions 0↔>0 in all tested
scenarios: step-from-idle, pause→step, pause-mid-step→resume. Wire protocol byte 10
renamed `inpos`→`paused` (carries `s.paused`), byte 9 renamed `task_paused`→`step_mode`.

### Section C program control (2026-04-20)
All six Section C keys implemented: Stop, Cycle Start, Pause, Single Step, M1 Optional Stop,
Coolant/Flood. motion_cmd bits: 0x01=start, 0x02=stop, 0x04=pause, 0x08=step,
0x10=opt_stop edge, 0x20=coolant edge.

### Homed state gating (2026-04-21)
`homed` byte in OUT packet. Program control buttons gated when not homed.
STOP LED (LED10) slow-blinks at 1s period when enabled but not homed.

### HACK cleanup session (2026-04-21)
HACK-2 through HACK-9 all resolved. See git history for details.

### LED queue depth bug (2026-04-21)
LED task cmd_queue raised from depth 10 → 32. Fixed LED 7 flush flag.

### hmi.py USB reconnection (prior)
Outer reconnect loop. Safe stop on disconnect. Status dict reset forces full re-sync on reconnect.
HAL knob seeded to current LinuxCNC values (not 0xFFFF) so first IN packet doesn't spuriously set overrides.

### Override knob startup sync — full rework (2026-04-22)
Replaced async `ENCODER_CMD_SYNC_ALL` with synchronous `sync_all_immediate()` /
`sync_value_immediate()` API on `TaskEncoder`. Extended mutex protection to shadow values.
Added `enc_user_moved[]` flags: encoders re-sync to host on every override change until the
user physically touches that knob. Added 150ms settle delay in `hmi.py` before seeding
`HAL['knob.*']`. See `doc/knob_startup_bug.md` for full root-cause analysis.

### HID interface selection fix (2026-04-22)
`hmi.py` `find_hid_device()` now filters by `interface_number==0` (Generic HID) then
`usage_page==0xFF00` as fallback, instead of non-deterministic `devlist[0]`. Eliminates
silent no-sync when the keyboard interface was picked. Added `cfg_pkt` write retry ×3.
Added `max_velocity` float rounding to suppress jitter-driven spurious status updates.

### STOP+CYCLE START chord: home all axes (2026-04-22)
Hold STOP then CYCLE START for 2 seconds (only when enabled and not homed) to trigger
`c.home(-1)` and pulse `hmi.home-all` → `halui.home-all`. STOP LED fast-blinks (4 Hz)
during countdown; both LEDs flash full brightness on fire. Bit 0x40 added to `motion_cmd`
byte. Guard: chord only active when `!estop && enabled && !homed`.

### Probe Basic (QtPyVCP) sim config (2026-04-22)
`linuxcnc/pb_sim/` — standalone config alongside `hmi_sim/` (AXIS).
- 3-axis XYZ, inch, same HMI bridge and wiring as hmi_sim
- `DISPLAY = probe_basic`; venv (`~/dev/venv/bin/`) prepended to PATH in `run_pb_sim.sh`
- HAL: `core_sim_3.hal` + `simulated_home_probe_basic_3.hal` + `spindle_sim.hal`
- Local `hallib/probe_basic_postgui.hal` loads `not names=pb-not` to avoid conflict
  with `hmi_wiring.hal`'s `names=hmi-not` (POSIX sim can't `loadrt` same module twice)
- `subroutines/`, `user_buttons/`, `user_dro_display/`, `custom_config.yml`,
  `user_atc_buttons/` all symlinked from `~/dev/probe_basic/configs/probe_basic/`

### hmi.home-all HAL pin (2026-04-22)
`hmi.home-all` BIT OUT pin added to hmi.py. Pulsed TRUE for one cycle on the
STOP+CYCLE-START chord (bit 0x40). Wired to `halui.home-all` in both
`hmi_sim/hmi_wiring.hal` and `pb_sim/hmi_wiring.hal`. This is the same
path Probe Basic's "REF ALL" button uses, so the UI tracks homing correctly.

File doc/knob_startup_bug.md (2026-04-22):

# Knob Startup Race Condition — FULLY RESOLVED (2026-04-22)

## Original Symptom
On fresh startup after USB connect, the first press of a knob toggle button
(rapidrate/maxvel/feedrate) did nothing.  The second press worked correctly.

## Root Cause (final)
A two-layer startup sequencing problem:

1. **LinuxCNC transitional packets (hmi.py side):** `s.feedrate/rapidrate/max_velocity`
   return 0.0 transiently during LinuxCNC initialization before settling to their real
   defaults.  The Python bridge was seeding `HAL['knob.*']` immediately on connect,
   capturing these zeros.  The first OUT packet therefore carried `feedrate=0, rapidrate=0,
   maxvel=0`.

2. **Firmware only synced encoders once (main.cc side):** The firmware performed an
   initial encoder sync on the *first* OUT packet only (`if (!initial_feedrate)`).
   With the transient zeros in that first packet, the encoder was committed to 0.
   Subsequent packets changed the values to their real defaults and updated the ring
   LEDs, but never re-synced the encoder — so `get_value()` still returned 0.
   The first button press then computed `cur=0, target=reset_seg` and "set" the
   encoder to its already-correct value, wasting the press.

## Resolution (2026-04-22 Round 4)

### Fix 1: hmi.py — 150ms stabilization delay
Before seeding `HAL['knob.*']`, sleep 150ms then re-poll so that LinuxCNC's
override values have settled to their real defaults.  This ensures the first OUT
packet carries correct segment values in the common case.

File: `linuxcnc/hmi.py` — reconnect block, before knob seed lines.

### Fix 2: firmware — per-encoder `enc_user_moved[]` flag + `sync_value_immediate()`
Belt-and-suspenders for cases where the Python delay is insufficient (e.g. very
slow LinuxCNC startup).

- `enc_user_moved[4]` in `main_task`: reset to false at every reconnect.
- Encoder event handler: sets `enc_user_moved[encoder]` when any enc 1–3 event
  fires (physical turn or button toggle).
- OUT packet handler: calls `task_encoder->sync_value_immediate(enc, value)` on
  every `feedrate_changed / rapidrate_changed / maxvel_changed` event *while*
  `enc_user_moved[enc]` is false.  Once the user touches a knob, that encoder is
  no longer chased.

### Fix 3: firmware — `sync_value_immediate()` API on TaskEncoder
Single-encoder synchronous mutex-protected setter added alongside the existing
`sync_all_immediate()`.  Bypasses the async cmd queue so `get_value()` returns
the correct value immediately (no 10ms wait for the encoder task loop).

### Architectural improvements (same session)
- `last_value[5]` promoted from a `task()` local to `m_last_value[5]` member of
  `TaskEncoder`, enabling `sync_*_immediate()` to update both `m_cur_values` and
  the change-detection shadow atomically under the mutex.
- Mutex coverage extended to protect `m_last_value` in all write paths
  (SET_VALUE, SET_VALUE_NOTIFY, SMART_SET_VALUE, hardware poll) — previously
  only `get_value()` reads were guarded.
- `ENCODER_CMD_SYNC_ALL` removed: replaced entirely by `sync_all_immediate()`
  (called at reconnect) and `sync_value_immediate()` (called on each override
  change while user hasn't moved the encoder).
- `cmd_t` simplified: union/sync struct removed now that SYNC_ALL is gone.

## Key Files
- `linuxcnc/hmi.py` — 150ms settle delay before knob seed
- `firmware/main.cc` — `enc_user_moved[]`, reconnect reset, OUT packet re-sync logic
- `firmware/task_encoder.hh` — `sync_value_immediate()` declaration, `m_last_value` member
- `firmware/task_encoder.cc` — `sync_value_immediate()` implementation, extended mutex coverage

## Prior Fix Rounds (context)
- **Round 1 (2026-04-21):** `m_last_values{0,0,0,0}` in encoder.cc; first OUT packet
  fully processed; IN packet gated on initial sync flags.
- **Round 2 (2026-04-22):** `set_value()` clamping double-scaling bug fixed.
- **Round 3 (2026-04-22):** `ENCODER_CMD_SYNC_ALL` for atomic 3-encoder batch sync
  (replaced by Round 4's synchronous API).

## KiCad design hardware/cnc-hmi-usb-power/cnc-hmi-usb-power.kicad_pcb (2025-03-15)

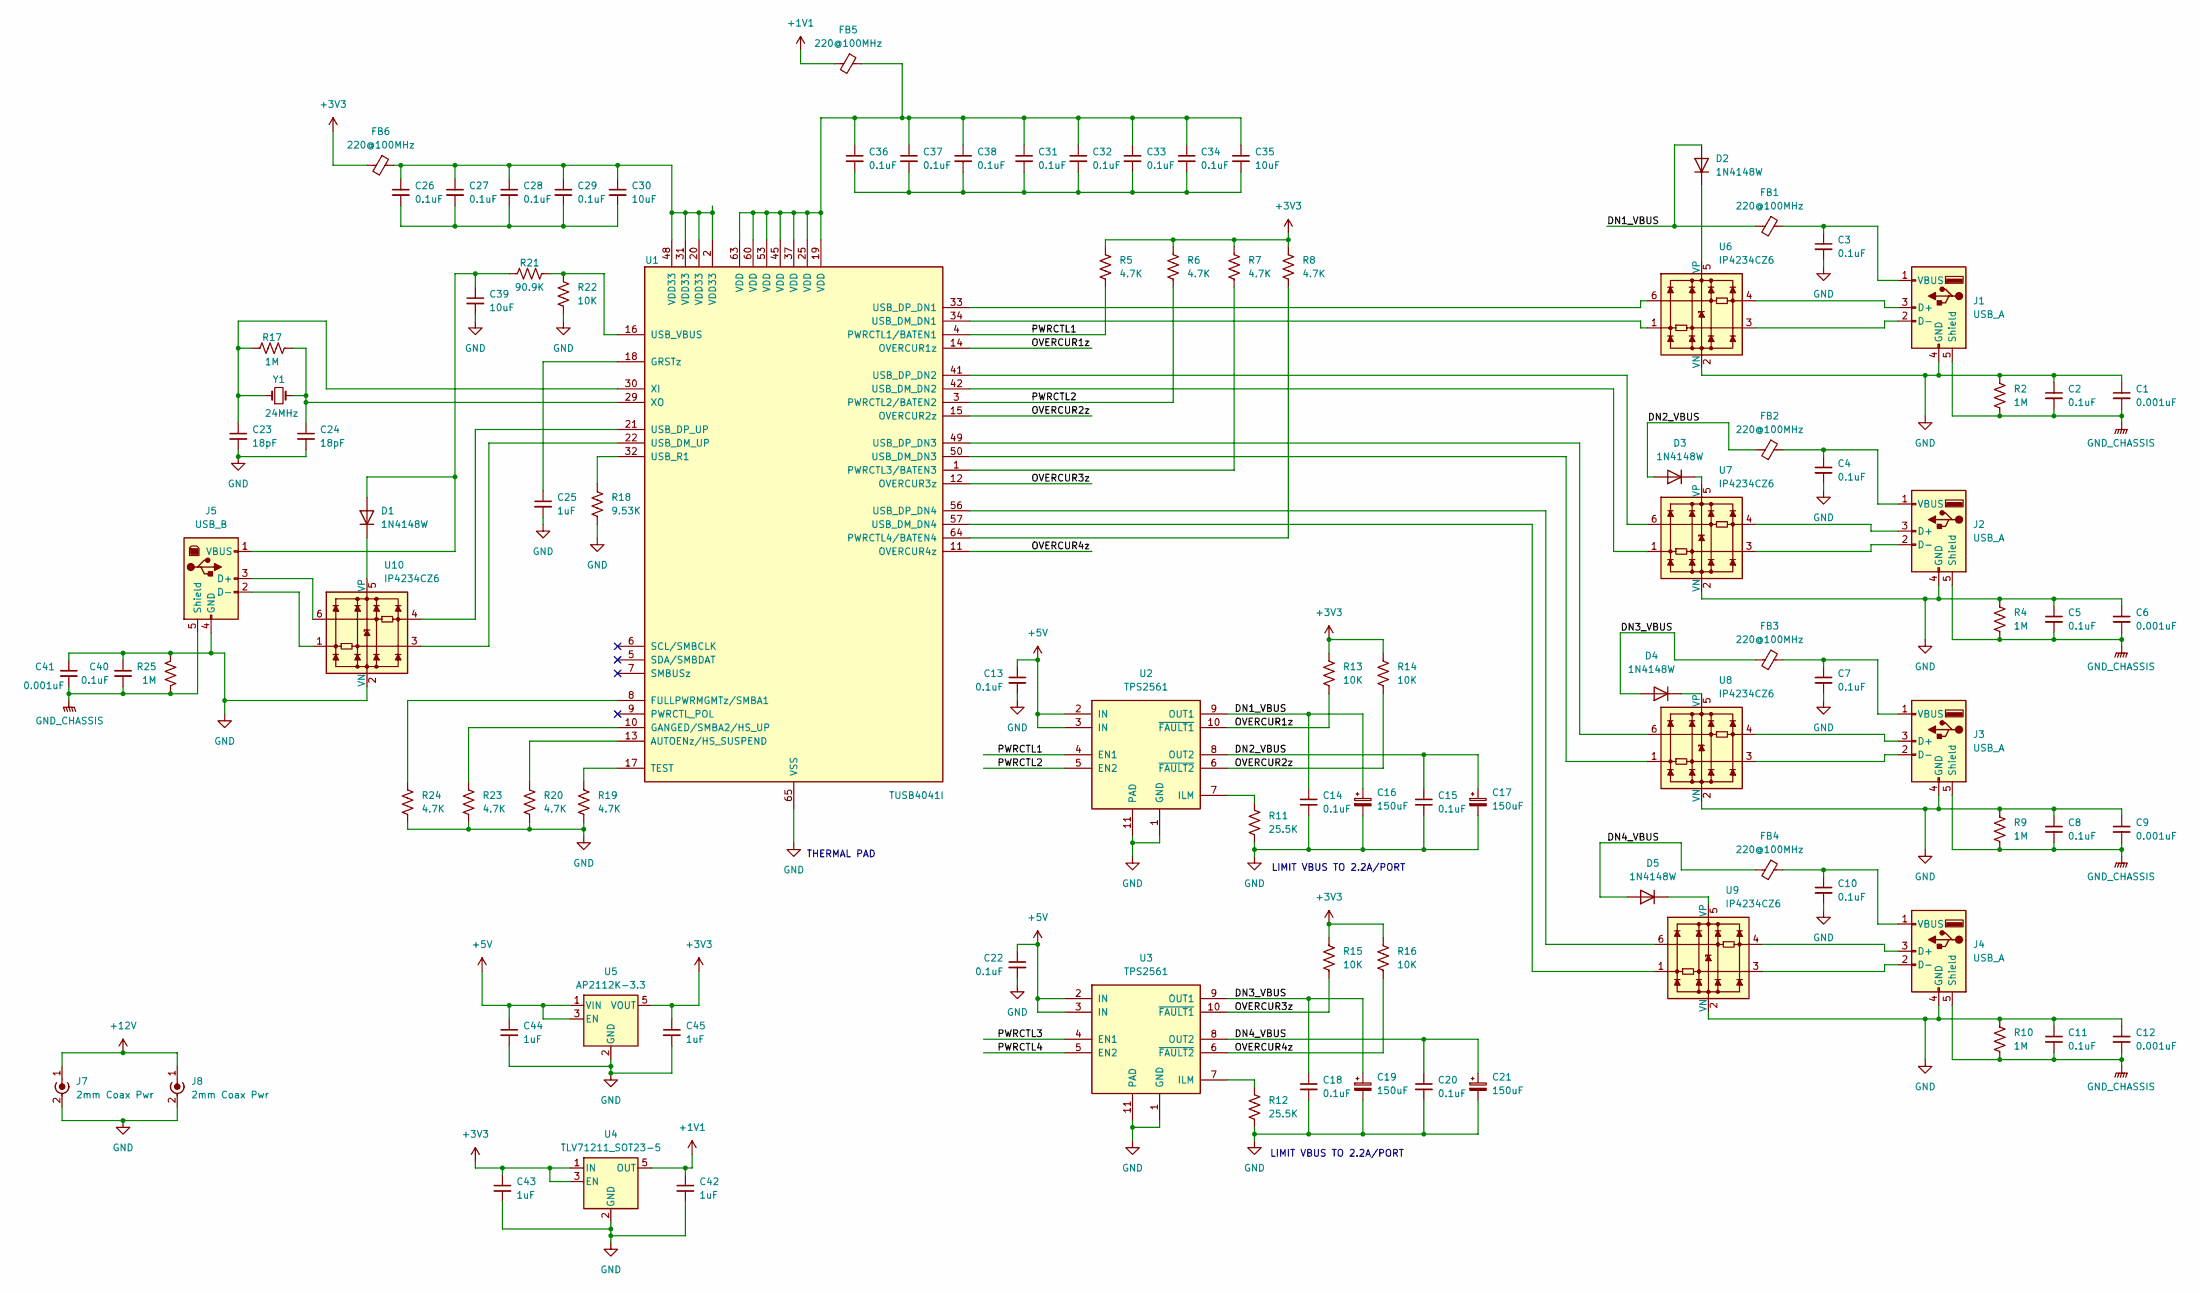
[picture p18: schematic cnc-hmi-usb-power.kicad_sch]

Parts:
C1, C6, C9, C12, C41: 0.001uF; C_0603_1608Metric
C2, C3, C4, C5, C7, C8, C10, C11, C13, C14, C15, C18, C20, C22, C26, C27, C28, C29, C31, C32, C33, C34, C36, C37, C38, C40: 0.1uF; C_0603_1608Metric
C16, C17, C19, C21: 150uF; CP_Elec_4x3
C23, C24: 18pF; C_0603_1608Metric
C25, C42, C43, C44, C45: 1uF; C_0805_2012Metric
C30, C35, C39: 10uF; C_0805_2012Metric
D1, D2, D3, D4, D5: 1N4148W; D_SOD-123
FB1, FB2, FB3, FB4, FB5, FB6: 220@100MHz; L_0805_2012Metric
J1, J2, J3, J4: USB_A; USB_A_Kycon_KUSBX-AS1N-B_Horizontal
J5: USB_B; USB_B_OST_USB-B1HSxx_Horizontal
J7, J8: 2mm Coax Pwr
R2, R4, R9, R10, R17, R25: 1M; R_0603_1608Metric
R5, R6, R7, R8, R19, R20, R23, R24: 4.7K; R_0603_1608Metric
R11, R12: 25.5K; R_0603_1608Metric
R13, R14, R15, R16, R22: 10K; R_0603_1608Metric
R18: 9.53K; R_0603_1608Metric
R21: 90.9K; R_0603_1608Metric
U1: TUSB4041I; HTQFP-64-1EP_10x10mm_P0.5mm_EP8x8mm_Mask4.4x4.4mm_ThermalVi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
U2, U3: TPS2561; VSON-10-1EP_3x3mm_P0.5mm_EP1.65x2.4mm_ThermalVias
U4: TLV71211_SOT23-5; SOT-23-5
U5: AP2112K-3.3; SOT-23-5
U6, U7, U8, U9, U10: IP4234CZ6; SC-74-6_1.55x2.9mm_P0.95mm
Y1: 24MHz; Crystal_SMD_0603-2Pin_6.0x3.5mm_HandSoldering

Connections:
+1V1: C42.1, FB5.2, U4.5 (OUT)
+3V3: C43.1, C45.1, FB6.2, R5.1, R6.1, R7.1, R8.1, R13.1, R14.1, R15.1, R16.1, U4.1 (IN), U4.3 (EN), U5.5 (VOUT)
+5V: C13.1, C22.1, C44.1, U2.2 (IN), U2.3 (IN), U3.2 (IN), U3.3 (IN), U5.1 (VIN), U5.3 (EN)
/DN1_VBUS: C14.1, C16.1, D2.2 (A), FB1.2, U2.9 (OUT1)
/DN2_VBUS: C15.1, C17.1, D3.2 (A), FB2.2, U2.8 (OUT2)
/DN3_VBUS: C18.1, C19.1, D4.2 (A), FB3.2, U3.9 (OUT1)
/DN4_VBUS: C20.1, C21.1, D5.2 (A), FB4.2, U3.8 (OUT2)
/OVERCUR1z: R13.2, U1.14 (OVERCUR1z), U2.10 (~FAULT1)
/OVERCUR2z: R14.2, U1.15 (OVERCUR2z), U2.6 (~FAULT2)
/OVERCUR3z: R15.2, U1.12 (OVERCUR3z), U3.10 (~FAULT1)
/OVERCUR4z: R16.2, U1.11 (OVERCUR4z), U3.6 (~FAULT2)
/PWRCTL1: R5.2, U1.4 (PWRCTL1/BATEN1), U2.4 (EN1)
/PWRCTL2: R6.2, U1.3 (PWRCTL2/BATEN2), U2.5 (EN2)
/PWRCTL3: U3.4 (EN1)
/PWRCTL4: U3.5 (EN2)
GND: C1.1, C2.1, C3.2, C4.2, C5.1, C6.1, C7.2, C8.1, C9.1, C10.2, C11.1, C12.1, C13.2, C14.2, C15.2, C16.2, C17.2, C18.2, C19.2, C20.2, C21.2, C22.2, C23.2, C24.2, C25.2, C39.2, C40.1, C41.1, C42.2, C43.2, C44.2, C45.2, J1.4 (GND), J2.4 (GND), J3.4 (GND), J4.4 (GND), J5.4 (GND), J7.2 (Ext), J8.2 (Ext), R2.1, R4.1, R9.1, R10.1, R11.2, R12.2, R18.2, R19.2, R20.2, R22.2, R23.2, R24.2, R25.1, U1.65 (VSS), U2.1 (GND), U2.11 (PAD), U3.1 (GND), U3.11 (PAD), U4.2 (GND), U5.2 (GND), U6.2 (VN), U7.2 (VN), U8.2 (VN), U9.2 (VN), U10.2 (VN)
GND_CHASSIS: C1.2, C2.2, C5.2, C6.2, C8.2, C9.2, C11.2, C12.2, C40.2, C41.2, J1.5 (Shield), J2.5 (Shield), J3.5 (Shield), J4.5 (Shield), J5.5 (Shield), R2.2, R4.2, R9.2, R10.2, R25.2
unnamed: C26.1, C27.1, C28.1, C29.1, C30.1, FB6.1, U1.2 (VDD33), U1.20 (VDD33), U1.31 (VDD33), U1.48 (VDD33)
unnamed: C26.2, C27.2, C28.2, C29.2, C30.2
unnamed: C31.1, C32.1, C33.1, C34.1, C35.1, C36.1, C37.1, C38.1, FB5.1, U1.19 (VDD), U1.25 (VDD), U1.37 (VDD), U1.45 (VDD), U1.53 (VDD), U1.60 (VDD), U1.63 (VDD)
unnamed: C31.2, C32.2, C33.2, C34.2, C35.2, C36.2, C37.2, C38.2
unnamed: C39.1, D1.2 (A), J5.1 (VBUS), R21.1
unnamed: D1.1 (K), U10.5 (VP)
unnamed: D2.1 (K), U6.5 (VP)
unnamed: D3.1 (K), U7.5 (VP)
unnamed: D4.1 (K), U8.5 (VP)
unnamed: D5.1 (K), U9.5 (VP)
unnamed: J1.3 (D+), U6.4
unnamed: J1.2 (D-), U6.3
unnamed: C3.1, FB1.1, J1.1 (VBUS)
unnamed: J2.3 (D+), U7.4
unnamed: J2.2 (D-), U7.3
unnamed: C4.1, FB2.1, J2.1 (VBUS)
unnamed: J3.3 (D+), U8.4
unnamed: J3.2 (D-), U8.3
unnamed: C7.1, FB3.1, J3.1 (VBUS)
unnamed: J4.3 (D+), U9.4
unnamed: J4.2 (D-), U9.3
unnamed: C10.1, FB4.1, J4.1 (VBUS)
unnamed: J5.3 (D+), U10.6
unnamed: J5.2 (D-), U10.1
unnamed: J7.1 (In), J8.1 (In)
unnamed: R20.1, U1.13 (AUTOENz/HS_SUSPEND)
unnamed: R24.1, U1.8 (FULLPWRMGMTz/SMBA1)
unnamed: R23.1, U1.10 (GANGED/SMBA2/HS_UP)
unnamed: C25.1, U1.18 (GRSTz)
unnamed: R7.2, U1.1 (PWRCTL3/BATEN3)
unnamed: R8.2, U1.64 (PWRCTL4/BATEN4)
unnamed: R19.1, U1.17 (TEST)
unnamed: U1.34 (USB_DM_DN1), U6.1
unnamed: U1.42 (USB_DM_DN2), U7.1
unnamed: U1.50 (USB_DM_DN3), U8.1
unnamed: U1.57 (USB_DM_DN4), U9.1
unnamed: U1.22 (USB_DM_UP), U10.3
unnamed: U1.33 (USB_DP_DN1), U6.6
unnamed: U1.41 (USB_DP_DN2), U7.6
unnamed: U1.49 (USB_DP_DN3), U8.6
unnamed: U1.56 (USB_DP_DN4), U9.6
unnamed: U1.21 (USB_DP_UP), U10.4
unnamed: R18.1, U1.32 (USB_R1)
unnamed: R21.2, R22.1, U1.16 (USB_VBUS)
unnamed: C23.1, R17.1, U1.30 (XI), Y1.1
unnamed: C24.1, R17.2, U1.29 (XO), Y1.2
unnamed: R11.1, U2.7 (ILM)
unnamed: R12.1, U3.7 (ILM)

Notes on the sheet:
LIMIT VBUS TO 2.2A/PORT
THERMAL PAD

Board: 2 copper layers, 95 parts (0 on the bottom side), 62 nets, no tracks yet.

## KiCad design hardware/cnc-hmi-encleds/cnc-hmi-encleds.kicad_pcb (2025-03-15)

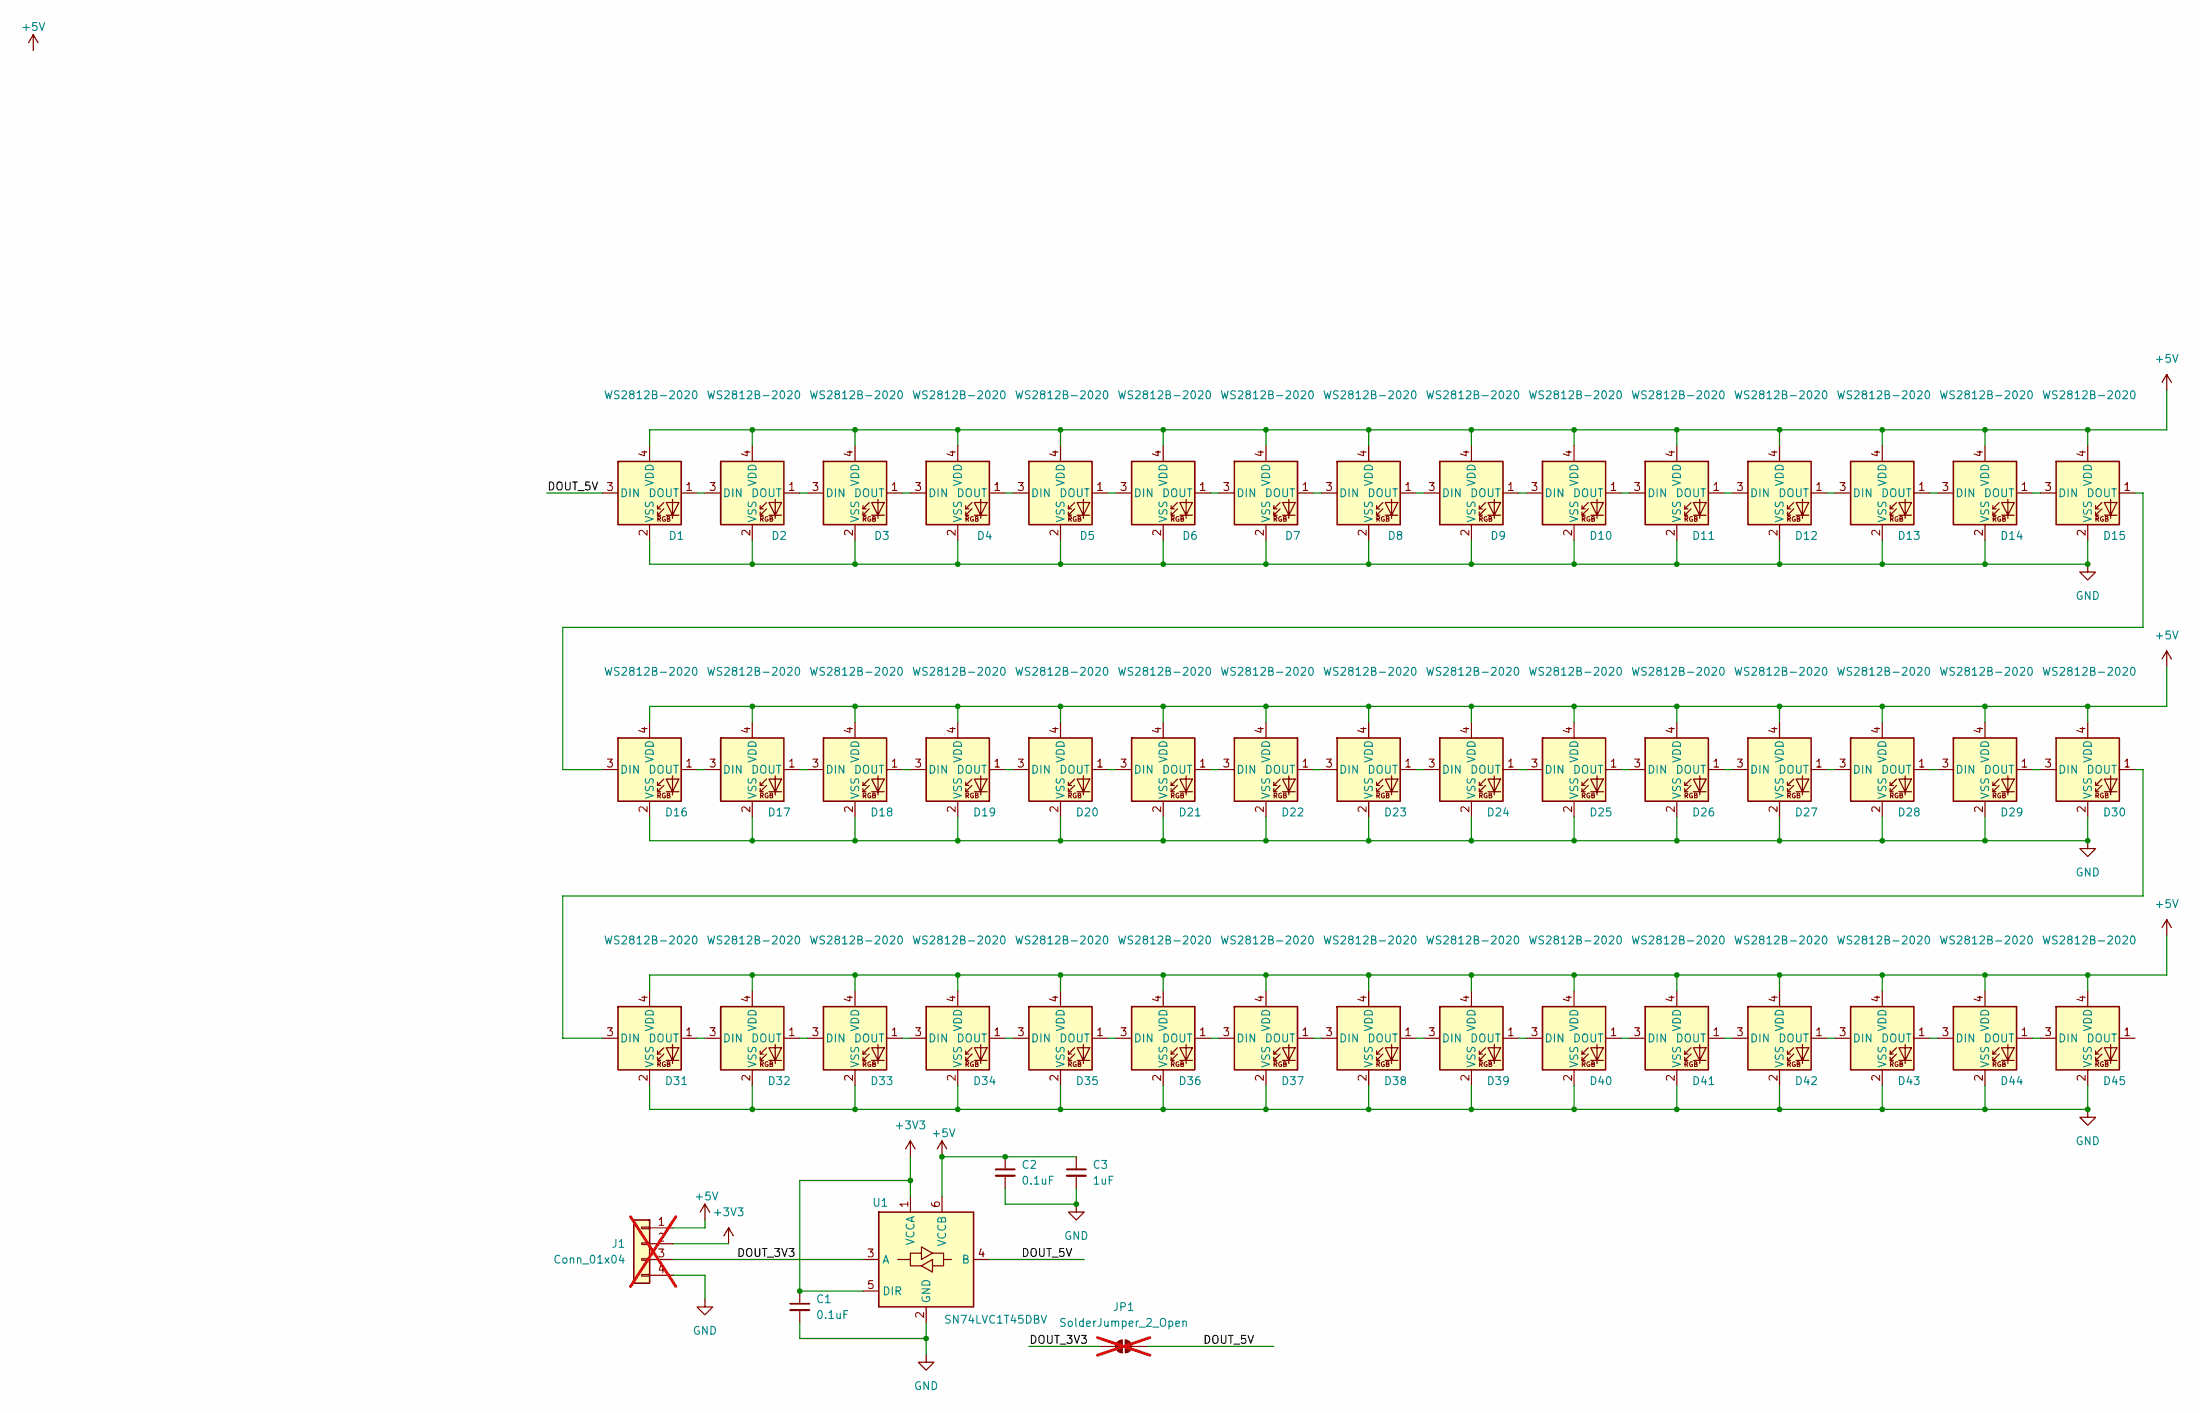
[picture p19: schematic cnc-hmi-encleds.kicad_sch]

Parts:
C1, C2: 0.1uF; C_0603_1608Metric; JLCPCB P/N C1590
C3: 1uF; C_0805_2012Metric; JLCPCB P/N C1712
D1, D2, D3, D4, D5, D6, D7, D8, D9, D10, D11, D12, D13, D14, D15, D16, D17, D18, D19, D20, D21, D22, D23, D24, D25, D26, D27, D28, D29, D30, D31, D32, D33, D34, D35, D36, D37, D38, D39, D40, D41, D42, D43, D44, D45: WS2812B-2020; LED_WS2812B-2020_PLCC4_2.0x2.0mm; JLCPCB P/N C965555
J1: Conn_01x04; JST_PH_B4B-PH-SM4-TB_1x04-1MP_P2.00mm_Vertical; not fitted
JP1: SolderJumper_2_Open; SolderJumper-2_P1.3mm_Open_TrianglePad1.0x1.5mm; not fitted
U1: SN74LVC1T45DBV; SOT-23-6; JLCPCB P/N C7843

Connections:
+3V3: C1.1, J1.2, U1.1 (VCCA), U1.5 (DIR)
+5V: C2.1, C3.1, D1.4 (VDD), D2.4 (VDD), D3.4 (VDD), D4.4 (VDD), D5.4 (VDD), D6.4 (VDD), D7.4 (VDD), D8.4 (VDD), D9.4 (VDD), D10.4 (VDD), D11.4 (VDD), D12.4 (VDD), D13.4 (VDD), D14.4 (VDD), D15.4 (VDD), D16.4 (VDD), D17.4 (VDD), D18.4 (VDD), D19.4 (VDD), D20.4 (VDD), D21.4 (VDD), D22.4 (VDD), D23.4 (VDD), D24.4 (VDD), D25.4 (VDD), D26.4 (VDD), D27.4 (VDD), D28.4 (VDD), D29.4 (VDD), D30.4 (VDD), D31.4 (VDD), D32.4 (VDD), D33.4 (VDD), D34.4 (VDD), D35.4 (VDD), D36.4 (VDD), D37.4 (VDD), D38.4 (VDD), D39.4 (VDD), D40.4 (VDD), D41.4 (VDD), D42.4 (VDD), D43.4 (VDD), D44.4 (VDD), D45.4 (VDD), J1.1, U1.6 (VCCB)
/DOUT_3V3: J1.3, JP1.1 (A), U1.3 (A)
/DOUT_5V: D1.3 (DIN), JP1.2 (B), U1.4 (B)
GND: C1.2, C2.2, C3.2, D1.2 (VSS), D2.2 (VSS), D3.2 (VSS), D4.2 (VSS), D5.2 (VSS), D6.2 (VSS), D7.2 (VSS), D8.2 (VSS), D9.2 (VSS), D10.2 (VSS), D11.2 (VSS), D12.2 (VSS), D13.2 (VSS), D14.2 (VSS), D15.2 (VSS), D16.2 (VSS), D17.2 (VSS), D18.2 (VSS), D19.2 (VSS), D20.2 (VSS), D21.2 (VSS), D22.2 (VSS), D23.2 (VSS), D24.2 (VSS), D25.2 (VSS), D26.2 (VSS), D27.2 (VSS), D28.2 (VSS), D29.2 (VSS), D30.2 (VSS), D31.2 (VSS), D32.2 (VSS), D33.2 (VSS), D34.2 (VSS), D35.2 (VSS), D36.2 (VSS), D37.2 (VSS), D38.2 (VSS), D39.2 (VSS), D40.2 (VSS), D41.2 (VSS), D42.2 (VSS), D43.2 (VSS), D44.2 (VSS), D45.2 (VSS), J1.4, U1.2 (GND)
unnamed: D1.1 (DOUT), D2.3 (DIN)
unnamed: D2.1 (DOUT), D3.3 (DIN)
unnamed: D3.1 (DOUT), D4.3 (DIN)
unnamed: D4.1 (DOUT), D5.3 (DIN)
unnamed: D5.1 (DOUT), D6.3 (DIN)
unnamed: D6.1 (DOUT), D7.3 (DIN)
unnamed: D7.1 (DOUT), D8.3 (DIN)
unnamed: D8.1 (DOUT), D9.3 (DIN)
unnamed: D9.1 (DOUT), D10.3 (DIN)
unnamed: D10.1 (DOUT), D11.3 (DIN)
unnamed: D11.1 (DOUT), D12.3 (DIN)
unnamed: D12.1 (DOUT), D13.3 (DIN)
unnamed: D13.1 (DOUT), D14.3 (DIN)
unnamed: D14.1 (DOUT), D15.3 (DIN)
unnamed: D15.1 (DOUT), D16.3 (DIN)
unnamed: D16.1 (DOUT), D17.3 (DIN)
unnamed: D17.1 (DOUT), D18.3 (DIN)
unnamed: D18.1 (DOUT), D19.3 (DIN)
unnamed: D19.1 (DOUT), D20.3 (DIN)
unnamed: D20.1 (DOUT), D21.3 (DIN)
unnamed: D21.1 (DOUT), D22.3 (DIN)
unnamed: D22.1 (DOUT), D23.3 (DIN)
unnamed: D23.1 (DOUT), D24.3 (DIN)
unnamed: D24.1 (DOUT), D25.3 (DIN)
unnamed: D25.1 (DOUT), D26.3 (DIN)
unnamed: D26.1 (DOUT), D27.3 (DIN)
unnamed: D27.1 (DOUT), D28.3 (DIN)
unnamed: D28.1 (DOUT), D29.3 (DIN)
unnamed: D29.1 (DOUT), D30.3 (DIN)
unnamed: D30.1 (DOUT), D31.3 (DIN)
unnamed: D31.1 (DOUT), D32.3 (DIN)
unnamed: D32.1 (DOUT), D33.3 (DIN)
unnamed: D33.1 (DOUT), D34.3 (DIN)
unnamed: D34.1 (DOUT), D35.3 (DIN)
unnamed: D35.1 (DOUT), D36.3 (DIN)
unnamed: D36.1 (DOUT), D37.3 (DIN)
unnamed: D37.1 (DOUT), D38.3 (DIN)
unnamed: D38.1 (DOUT), D39.3 (DIN)
unnamed: D39.1 (DOUT), D40.3 (DIN)
unnamed: D40.1 (DOUT), D41.3 (DIN)
unnamed: D41.1 (DOUT), D42.3 (DIN)
unnamed: D42.1 (DOUT), D43.3 (DIN)
unnamed: D43.1 (DOUT), D44.3 (DIN)
unnamed: D44.1 (DOUT), D45.3 (DIN)

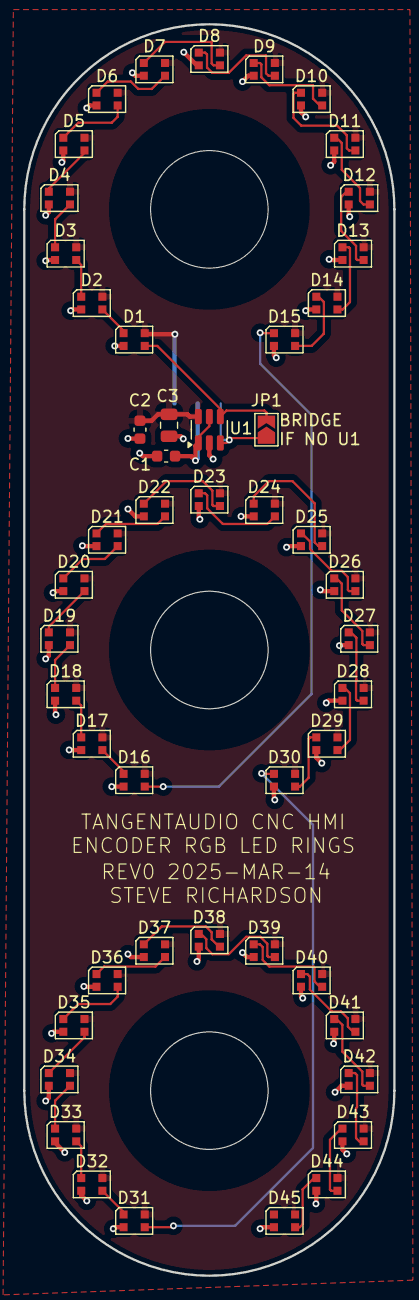
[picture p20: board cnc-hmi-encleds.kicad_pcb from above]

Board: 2 copper layers, 32.0 x 108.2 mm, 51 parts (1 on the bottom side), 49 nets.

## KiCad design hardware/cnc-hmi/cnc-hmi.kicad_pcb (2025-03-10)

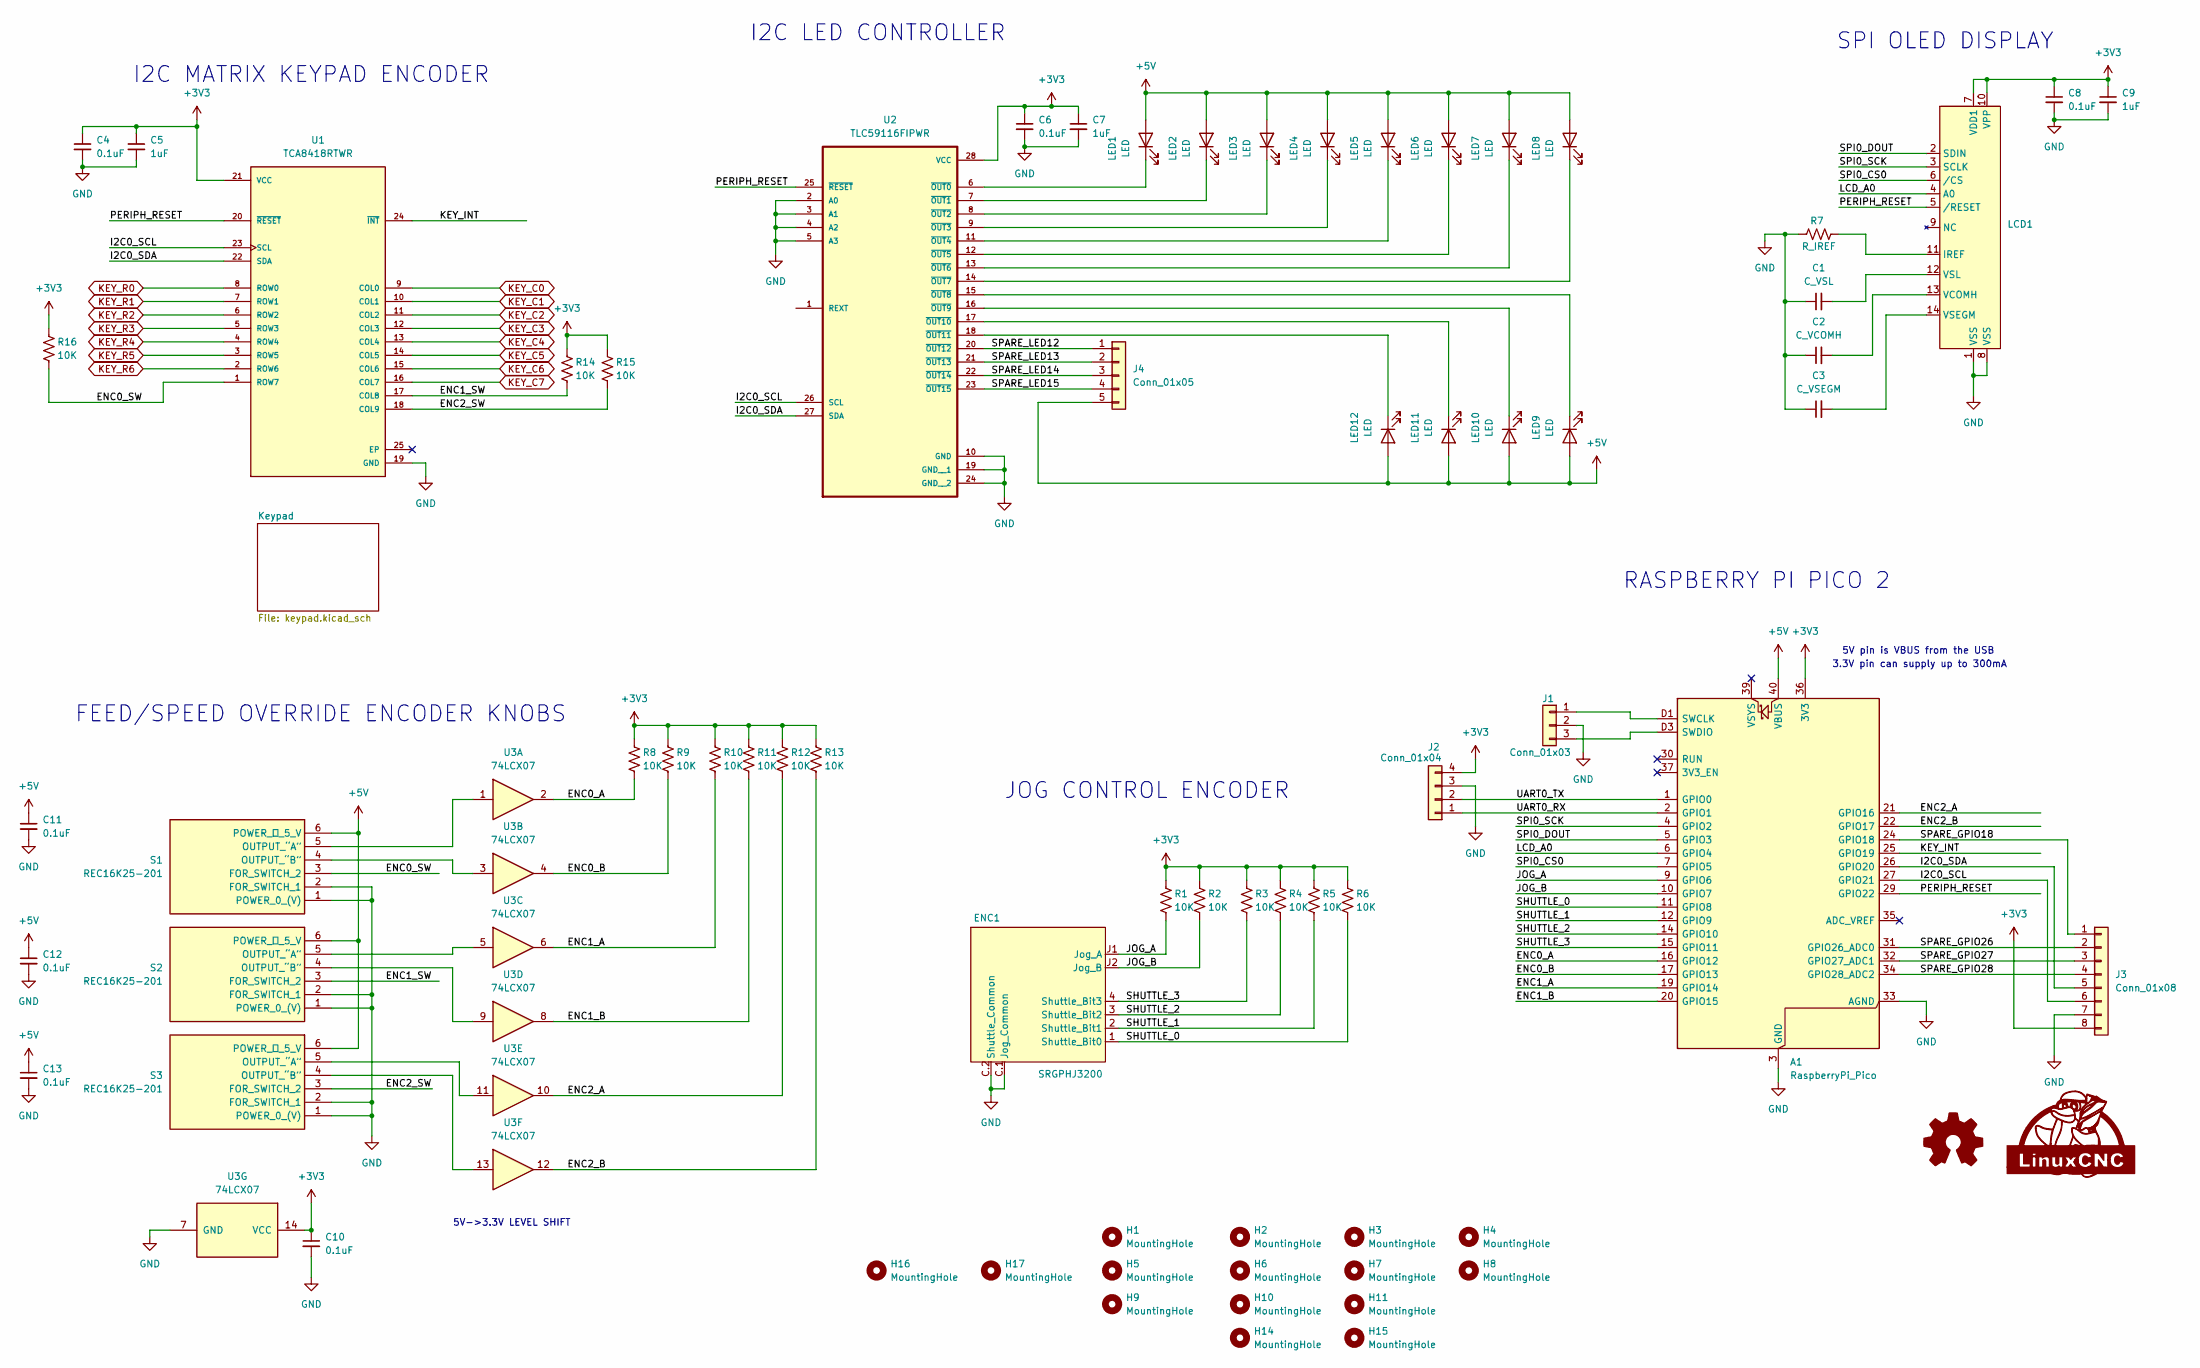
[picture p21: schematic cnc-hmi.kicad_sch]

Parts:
A1: RaspberryPi_Pico; RaspberryPi_Pico2_SMD_HandSolder
C1: C_VSL; C_0805_2012Metric_Pad1.18x1.45mm_HandSolder
C2: C_VCOMH; C_0805_2012Metric_Pad1.18x1.45mm_HandSolder
C3: C_VSEGM; C_0805_2012Metric_Pad1.18x1.45mm_HandSolder
C4, C6, C8, C10, C11, C12, C13: 0.1uF; C_0603_1608Metric
C5, C7, C9: 1uF; C_0805_2012Metric
ENC1: SRGPHJ3200
H1, H2, H3, H4, H5, H6, H7, H8, H9, H10, H11, H14, H15: MountingHole; M3-Mounting Hole
H16, H17: MountingHole; M2.5-Mounting Hole
J1: Conn_01x03; JST_PH_S3B-PH-K_1x03_P2.00mm_Horizontal
J2: Conn_01x04; JST_PH_S4B-PH-K_1x04_P2.00mm_Horizontal
J3: Conn_01x08; JST_PH_S8B-PH-K_1x08_P2.00mm_Horizontal
J4: Conn_01x05; JST_PH_S5B-PH-K_1x05_P2.00mm_Horizontal
LCD1: ER-CON14HT-1
LED1, LED2, LED3, LED4, LED5, LED6, LED7, LED8, LED9, LED10, LED11, LED12: LED; MX-LED-Reversed
LOGO1: LinuxCNC Logo
LOGO2: Logo_Open_Hardware_Small; OSHW-Logo_11.4x12mm_SilkScreen
R1, R2, R3, R4, R5, R6, R8, R9, R10, R11, R12, R13, R14, R15, R16: 10K; R_0603_1608Metric
R7: R_IREF; R_0603_1608Metric
S1, S2, S3: REC16K25-201; REC16K25201; Manufacturer_Part_Number REC16K25-201
U1: TCA8418RTWR; QFN50P400X400X80-25N; PARTREV G
U2: TLC59116FIPWR; SOP65P640X120-28N
U3: 74LCX07; SOIC-14_3.9x8.7mm_P1.27mm

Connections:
+3V3: A1.36 (3V3), C4.1, C5.1, C6.1, C7.1, C8.1, C9.1, C10.1, J2.4, J3.8, LCD1.7 (VDD1), LCD1.10 (VPP), R1.1, R2.1, R3.1, R4.1, R5.1, R6.1, R8.1, R9.1, R10.1, R11.1, R12.1, R13.1, R14.1, R15.1, R16.1, U1.21 (VCC), U2.28 (VCC), U3.14 (VCC)
+5V: A1.40 (VBUS), C11.1, C12.1, C13.1, J4.5, LED1.2 (A), LED2.2 (A), LED3.2 (A), LED4.2 (A), LED5.2 (A), LED6.2 (A), LED7.2 (A), LED8.2 (A), LED9.2 (A), LED10.2 (A), LED11.2 (A), LED12.2 (A), S1.6 (POWER_＋_5_V), S2.6 (POWER_＋_5_V), S3.6 (POWER_＋_5_V)
/ENC0_A: A1.16 (GPIO12), R8.2, U3.2
/ENC0_B: A1.17 (GPIO13), R9.2, U3.4
/ENC0_SW: R16.2, S1.3 (FOR_SWITCH_2), U1.1 (ROW7)
/ENC1_A: A1.19 (GPIO14), R10.2, U3.6
/ENC1_B: A1.20 (GPIO15), R11.2, U3.8
/ENC1_SW: R14.2, S2.3 (FOR_SWITCH_2), U1.17 (COL8)
/ENC2_A: A1.21 (GPIO16), R12.2, U3.10
/ENC2_B: A1.22 (GPIO17), R13.2, U3.12
/ENC2_SW: R15.2, S3.3 (FOR_SWITCH_2), U1.18 (COL9)
/I2C0_SCL: A1.27 (GPIO21), J3.6, U1.23 (SCL), U2.26 (SCL)
/I2C0_SDA: A1.26 (GPIO20), J3.5, U1.22 (SDA), U2.27 (SDA)
/JOG_A: A1.9 (GPIO6), ENC1.J1 (Jog_A), R1.2
/JOG_B: A1.10 (GPIO7), ENC1.J2 (Jog_B), R2.2
/KEY_INT: A1.25 (GPIO19), U1.24 (~INT)
/LCD_A0: A1.6 (GPIO4), LCD1.4 (A0)
/PERIPH_RESET: A1.29 (GPIO22), LCD1.5 (/RESET), U1.20 (~RESET), U2.25 (~RESET)
/SHUTTLE_0: A1.11 (GPIO8), ENC1.1 (Shuttle_Bit0), R6.2
/SHUTTLE_1: A1.12 (GPIO9), ENC1.2 (Shuttle_Bit1), R5.2
/SHUTTLE_2: A1.14 (GPIO10), ENC1.3 (Shuttle_Bit2), R4.2
/SHUTTLE_3: A1.15 (GPIO11), ENC1.4 (Shuttle_Bit3), R3.2
/SPARE_GPIO18: A1.24 (GPIO18), J3.1
/SPARE_GPIO26: A1.31 (GPIO26_ADC0), J3.2
/SPARE_GPIO27: A1.32 (GPIO27_ADC1), J3.3
/SPARE_GPIO28: A1.34 (GPIO28_ADC2), J3.4
/SPARE_LED12: J4.1, U2.20 (~OUT12)
/SPARE_LED13: J4.2, U2.21 (~OUT13)
/SPARE_LED14: J4.3, U2.22 (~OUT14)
/SPARE_LED15: J4.4, U2.23 (~OUT15)
/SPI0_CS0: A1.7 (GPIO5), LCD1.6 (/CS)
/SPI0_DOUT: A1.5 (GPIO3), LCD1.2 (SDIN)
/SPI0_SCK: A1.4 (GPIO2), LCD1.3 (SCLK)
/UART0_RX: A1.2 (GPIO1), J2.1
/UART0_TX: A1.1 (GPIO0), J2.2
GND: A1.3 (GND), A1.8 (GND), A1.13 (GND), A1.18 (GND), A1.23 (GND), A1.28 (GND), A1.33 (AGND), A1.38 (GND), A1.D2 (GND), C1.1, C2.1, C3.1, C4.2, C5.2, C6.2, C7.2, C8.2, C9.2, C10.2, C11.2, C12.2, C13.2, ENC1.C.1 (Jog_Common), ENC1.C.2 (Shuttle_Common), J1.2, J2.3, J3.7, LCD1.1 (VSS), LCD1.8 (VSS), R7.1, S1.1 (POWER_0_(V)), S1.2 (FOR_SWITCH_1), S2.1 (POWER_0_(V)), S2.2 (FOR_SWITCH_1), S3.1 (POWER_0_(V)), S3.2 (FOR_SWITCH_1), U1.19 (GND), U2.2 (A0), U2.3 (A1), U2.4 (A2), U2.5 (A3), U2.10 (GND), U2.19 (GND__1), U2.24 (GND__2), U3.7 (GND)
KEY_C0: U1.9 (COL0); also elsewhere on the board
KEY_C1: U1.10 (COL1); also elsewhere on the board
KEY_C2: U1.11 (COL2); also elsewhere on the board
KEY_C3: U1.12 (COL3); also elsewhere on the board
KEY_C4: U1.13 (COL4); also elsewhere on the board
KEY_C5: U1.14 (COL5); also elsewhere on the board
KEY_C6: U1.15 (COL6); also elsewhere on the board
KEY_C7: U1.16 (COL7); also elsewhere on the board
KEY_R0: U1.8 (ROW0); also elsewhere on the board
KEY_R1: U1.7 (ROW1); also elsewhere on the board
KEY_R2: U1.6 (ROW2); also elsewhere on the board
KEY_R3: U1.5 (ROW3); also elsewhere on the board
KEY_R4: U1.4 (ROW4); also elsewhere on the board
KEY_R5: U1.3 (ROW5); also elsewhere on the board
KEY_R6: U1.2 (ROW6); also elsewhere on the board
unnamed: A1.D1 (SWCLK), J1.1
unnamed: A1.D3 (SWDIO), J1.3
unnamed: LCD1.11 (IREF), R7.2
unnamed: C2.2, LCD1.13 (VCOMH)
unnamed: C3.2, LCD1.14 (VSEGM)
unnamed: C1.2, LCD1.12 (VSL)
unnamed: LED1.1 (K), U2.6 (~OUT0)
unnamed: LED2.1 (K), U2.7 (~OUT1)
unnamed: LED3.1 (K), U2.8 (~OUT2)
unnamed: LED4.1 (K), U2.9 (~OUT3)
unnamed: LED5.1 (K), U2.11 (~OUT4)
unnamed: LED6.1 (K), U2.12 (~OUT5)
unnamed: LED7.1 (K), U2.13 (~OUT6)
unnamed: LED8.1 (K), U2.14 (~OUT7)
unnamed: LED9.1 (K), U2.15 (~OUT8)
unnamed: LED10.1 (K), U2.16 (~OUT9)
unnamed: LED11.1 (K), U2.17 (~OUT10)
unnamed: LED12.1 (K), U2.18 (~OUT11)
unnamed: S1.5 (OUTPUT_“A”), U3.1
unnamed: S1.4 (OUTPUT_“B”), U3.3
unnamed: S2.5 (OUTPUT_“A”), U3.5
unnamed: S2.4 (OUTPUT_“B”), U3.9
unnamed: S3.5 (OUTPUT_“A”), U3.11
unnamed: S3.4 (OUTPUT_“B”), U3.13

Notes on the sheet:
3.3V pin can supply up to 300mA
SPI OLED DISPLAY
FEED/SPEED OVERRIDE ENCODER KNOBS
RASPBERRY PI PICO 2
5V->3.3V LEVEL SHIFT
JOG CONTROL ENCODER
5V pin is VBUS from the USB
I2C LED CONTROLLER
I2C MATRIX KEYPAD ENCODER

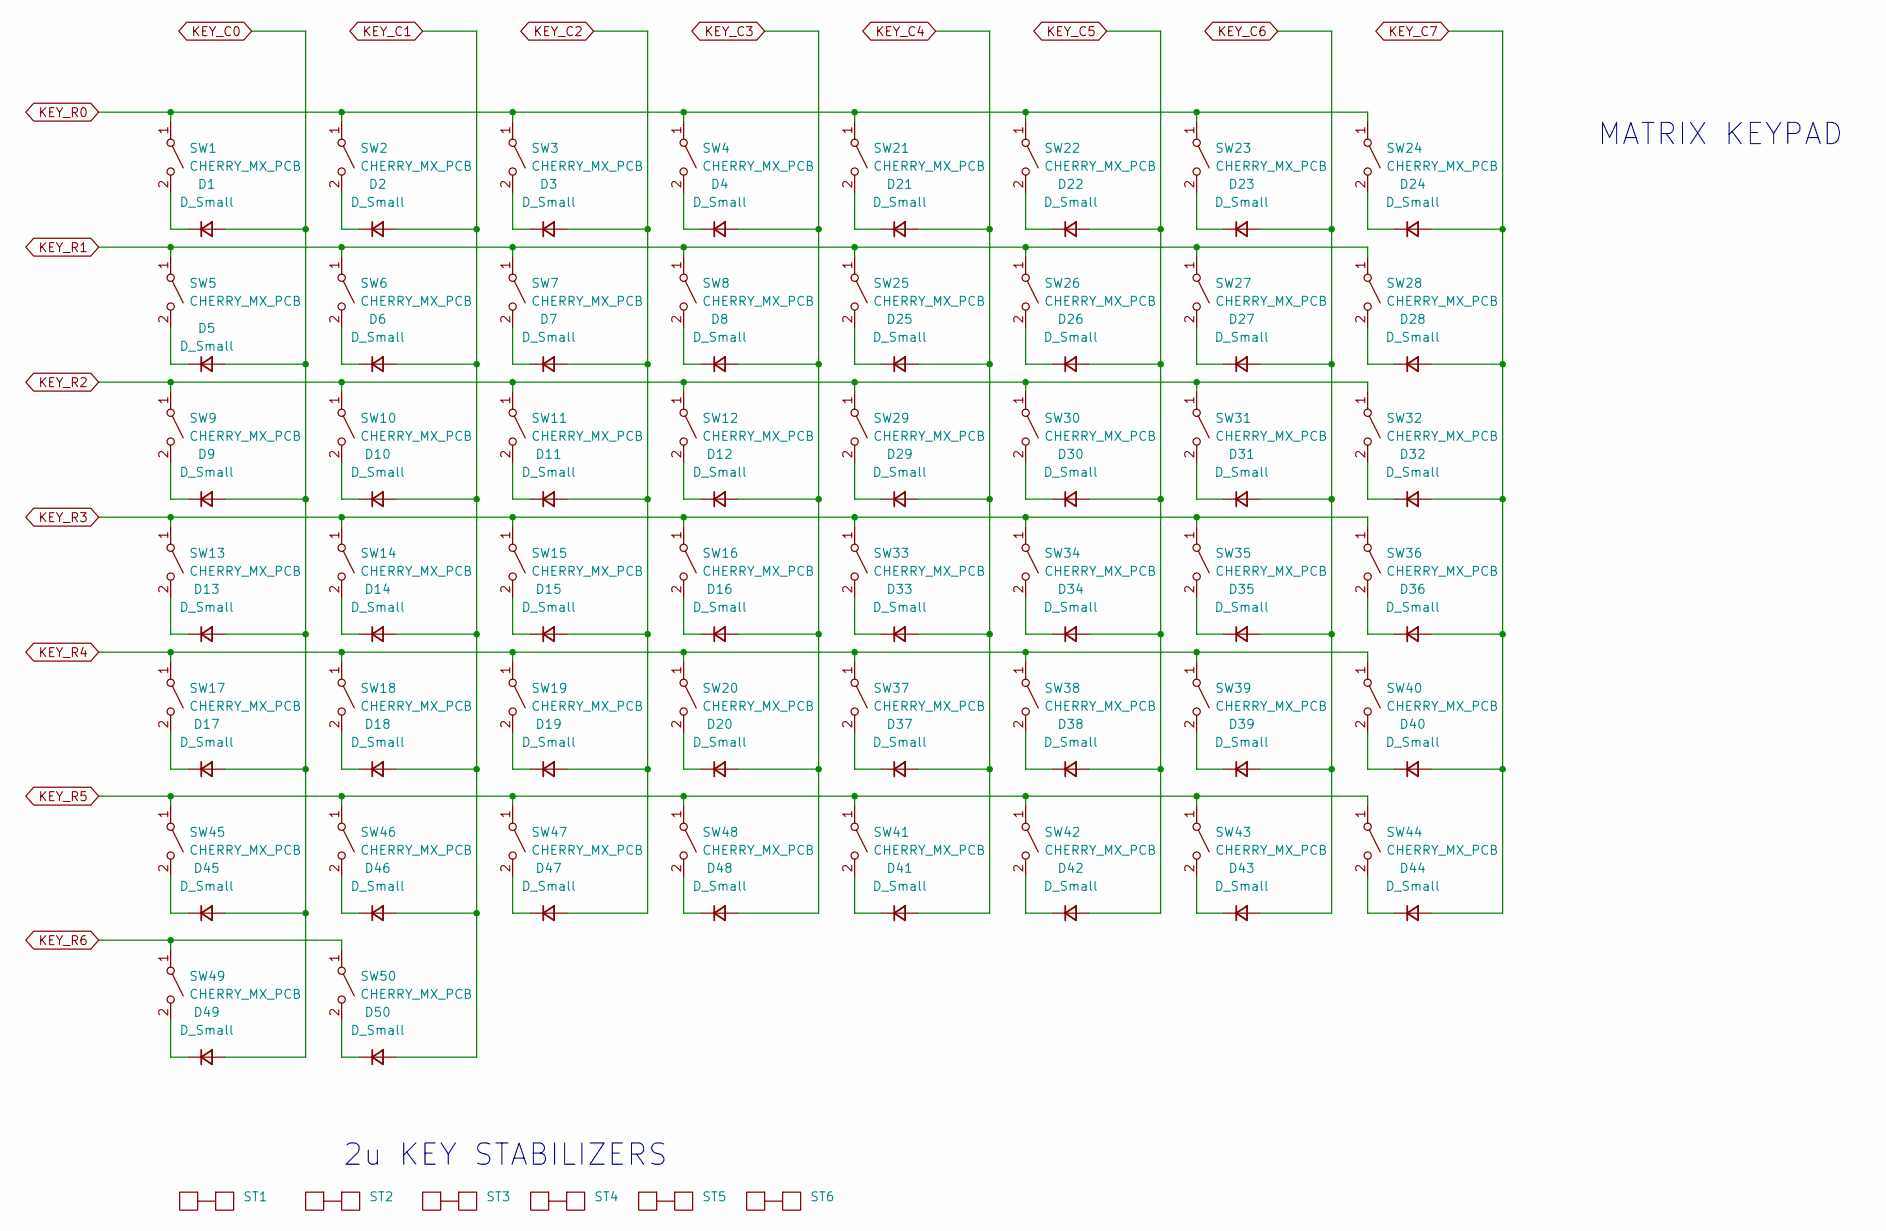
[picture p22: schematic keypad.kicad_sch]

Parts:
D1, D2, D3, D4, D5, D6, D7, D8, D9, D10, D11, D12, D13, D14, D15, D16, D17, D18, D19, D20, D21, D22, D23, D24, D25, D26, D27, D28, D29, D30, D31, D32, D33, D34, D35, D36, D37, D38, D39, D40, D41, D42, D43, D44, D45, D46, D47, D48, D49, D50: D_Small; D_SOD-523
ST1, ST2, ST3, ST4, ST5, ST6: Stabilizer_Cherry_MX_2.00u
SW1, SW2, SW3, SW4, SW5, SW6, SW7, SW8, SW9, SW10, SW11, SW12, SW13, SW14, SW15, SW17, SW18, SW19, SW20, SW21, SW22, SW23, SW24, SW25, SW26, SW27, SW28, SW29, SW30, SW31, SW32, SW33, SW34, SW35, SW36, SW37, SW39, SW40, SW41, SW42, SW43, SW44, SW49, SW50: CHERRY_MX_PCB; SW_Cherry_MX_PCB_1.00u
SW16: CHERRY_MX_PCB; SW_Cherry_MX_PCB_2.00u_90deg
SW38, SW45, SW46, SW47, SW48: CHERRY_MX_PCB; SW_Cherry_MX_PCB_2.00u

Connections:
KEY_C0: D1.2 (A), D5.2 (A), D9.2 (A), D13.2 (A), D17.2 (A), D45.2 (A), D49.2 (A); also elsewhere on the board
KEY_C1: D2.2 (A), D6.2 (A), D10.2 (A), D14.2 (A), D18.2 (A), D46.2 (A), D50.2 (A); also elsewhere on the board
KEY_C2: D3.2 (A), D7.2 (A), D11.2 (A), D15.2 (A), D19.2 (A), D47.2 (A); also elsewhere on the board
KEY_C3: D4.2 (A), D8.2 (A), D12.2 (A), D16.2 (A), D20.2 (A), D48.2 (A); also elsewhere on the board
KEY_C4: D21.2 (A), D25.2 (A), D29.2 (A), D33.2 (A), D37.2 (A), D41.2 (A); also elsewhere on the board
KEY_C5: D22.2 (A), D26.2 (A), D30.2 (A), D34.2 (A), D38.2 (A), D42.2 (A); also elsewhere on the board
KEY_C6: D23.2 (A), D27.2 (A), D31.2 (A), D35.2 (A), D39.2 (A), D43.2 (A); also elsewhere on the board
KEY_C7: D24.2 (A), D28.2 (A), D32.2 (A), D36.2 (A), D40.2 (A), D44.2 (A); also elsewhere on the board
KEY_R0: SW1.1 (A), SW2.1 (A), SW3.1 (A), SW4.1 (A), SW21.1 (A), SW22.1 (A), SW23.1 (A), SW24.1 (A); also elsewhere on the board
KEY_R1: SW5.1 (A), SW6.1 (A), SW7.1 (A), SW8.1 (A), SW25.1 (A), SW26.1 (A), SW27.1 (A), SW28.1 (A); also elsewhere on the board
KEY_R2: SW9.1 (A), SW10.1 (A), SW11.1 (A), SW12.1 (A), SW29.1 (A), SW30.1 (A), SW31.1 (A), SW32.1 (A); also elsewhere on the board
KEY_R3: SW13.1 (A), SW14.1 (A), SW15.1 (A), SW16.1 (A), SW33.1 (A), SW34.1 (A), SW35.1 (A), SW36.1 (A); also elsewhere on the board
KEY_R4: SW17.1 (A), SW18.1 (A), SW19.1 (A), SW20.1 (A), SW37.1 (A), SW38.1 (A), SW39.1 (A), SW40.1 (A); also elsewhere on the board
KEY_R5: SW41.1 (A), SW42.1 (A), SW43.1 (A), SW44.1 (A), SW45.1 (A), SW46.1 (A), SW47.1 (A), SW48.1 (A); also elsewhere on the board
KEY_R6: SW49.1 (A), SW50.1 (A); also elsewhere on the board
unnamed: D1.1 (K), SW1.2 (B)
unnamed: D2.1 (K), SW2.2 (B)
unnamed: D3.1 (K), SW3.2 (B)
unnamed: D4.1 (K), SW4.2 (B)
unnamed: D5.1 (K), SW5.2 (B)
unnamed: D6.1 (K), SW6.2 (B)
unnamed: D7.1 (K), SW7.2 (B)
unnamed: D8.1 (K), SW8.2 (B)
unnamed: D9.1 (K), SW9.2 (B)
unnamed: D10.1 (K), SW10.2 (B)
unnamed: D11.1 (K), SW11.2 (B)
unnamed: D12.1 (K), SW12.2 (B)
unnamed: D13.1 (K), SW13.2 (B)
unnamed: D14.1 (K), SW14.2 (B)
unnamed: D15.1 (K), SW15.2 (B)
unnamed: D16.1 (K), SW16.2 (B)
unnamed: D17.1 (K), SW17.2 (B)
unnamed: D18.1 (K), SW18.2 (B)
unnamed: D19.1 (K), SW19.2 (B)
unnamed: D20.1 (K), SW20.2 (B)
unnamed: D21.1 (K), SW21.2 (B)
unnamed: D22.1 (K), SW22.2 (B)
unnamed: D23.1 (K), SW23.2 (B)
unnamed: D24.1 (K), SW24.2 (B)
unnamed: D25.1 (K), SW25.2 (B)
unnamed: D26.1 (K), SW26.2 (B)
unnamed: D27.1 (K), SW27.2 (B)
unnamed: D28.1 (K), SW28.2 (B)
unnamed: D29.1 (K), SW29.2 (B)
unnamed: D30.1 (K), SW30.2 (B)
unnamed: D31.1 (K), SW31.2 (B)
unnamed: D32.1 (K), SW32.2 (B)
unnamed: D33.1 (K), SW33.2 (B)
unnamed: D34.1 (K), SW34.2 (B)
unnamed: D35.1 (K), SW35.2 (B)
unnamed: D36.1 (K), SW36.2 (B)
unnamed: D37.1 (K), SW37.2 (B)
unnamed: D38.1 (K), SW38.2 (B)
unnamed: D39.1 (K), SW39.2 (B)
unnamed: D40.1 (K), SW40.2 (B)
unnamed: D41.1 (K), SW41.2 (B)
unnamed: D42.1 (K), SW42.2 (B)
unnamed: D43.1 (K), SW43.2 (B)
unnamed: D44.1 (K), SW44.2 (B)
unnamed: D45.1 (K), SW45.2 (B)
unnamed: D46.1 (K), SW46.2 (B)
unnamed: D47.1 (K), SW47.2 (B)
unnamed: D48.1 (K), SW48.2 (B)
unnamed: D49.1 (K), SW49.2 (B)
unnamed: D50.1 (K), SW50.2 (B)

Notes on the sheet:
MATRIX KEYPAD
2u KEY STABILIZERS

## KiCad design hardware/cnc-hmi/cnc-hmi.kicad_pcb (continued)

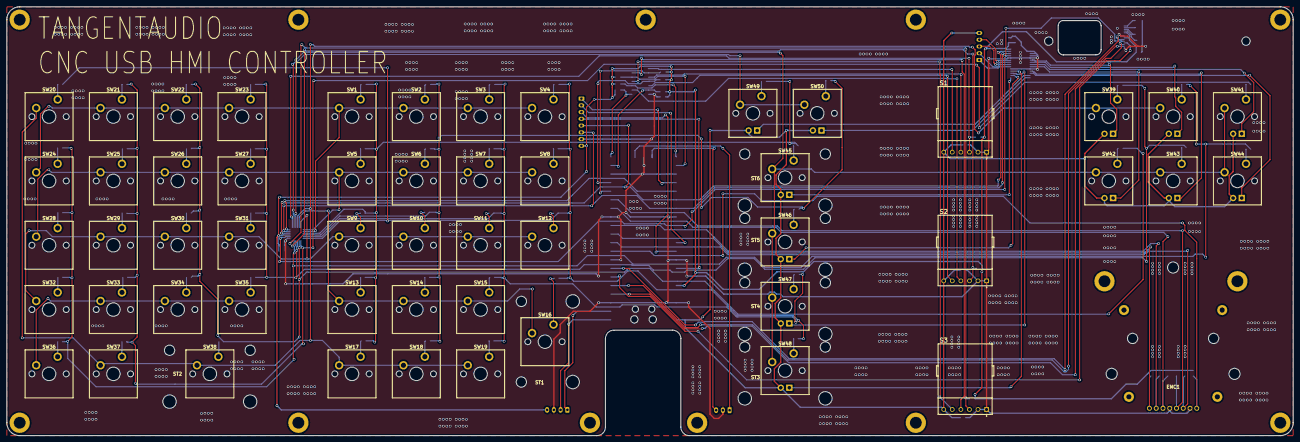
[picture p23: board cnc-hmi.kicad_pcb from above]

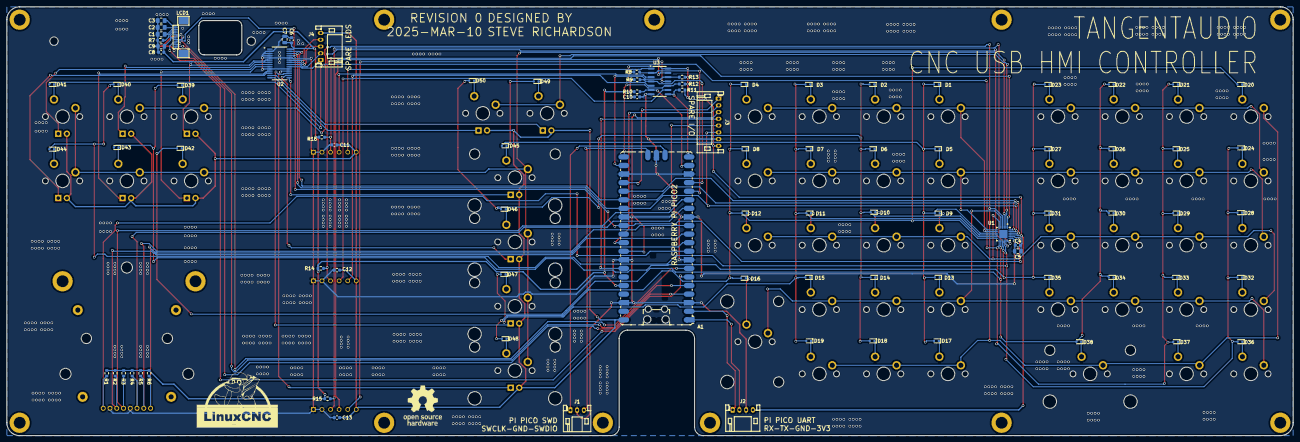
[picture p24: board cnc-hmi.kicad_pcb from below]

Board: 2 copper layers, 381.0 x 127.0 mm, 177 parts (90 on the bottom side), 125 nets.

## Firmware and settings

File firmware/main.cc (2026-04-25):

// PICO 2 GPIO MAP HW REV0
// =======================
// GPIO  0 - UART0 TX
// GPIO  1 - UART0 RX
// GPIO  2 - SPI0_SCK
// GPIO  3 - SPI0_DOUT
// GPIO  4 - LCD_A0
// GPIO  5 - SPI0_CS0
// GPIO  6 - JOG_A
// GPIO  7 - JOG_B
// GPIO  8 - SHUTTLE_0
// GPIO  9 - SHUTTLE_1
// GPIO 10 - SHUTTLE_2
// GPIO 11 - SHUTTLE_3
// GPIO 12 - ENC0_A
// GPIO 13 - ENC0_B
// GPIO 14 - ENC1_A
// GPIO 15 - ENC1_B
// GPIO 16 - ENC2_A
// GPIO 17 - ENC2_B
// GPIO 18 - SPARE
// GPIO 19 - /KEY_INT
// GPIO 20 - I2C0_SDA
// GPIO 21 - I2C0_SCL
// GPIO 22 - /PERIPH_RESET
// GPIO 26 - SPARE
// GPIO 27 - SPARE
// GPIO 28 - SPARE

#include <stdlib.h>
#include <stdio.h>
#include <string.h>
#include <FreeRTOS.h>
#include <task.h>
#include <queue.h>
#include <timers.h>
#include <boards/pico.h>
#include "pico/stdlib.h"
#include "pico/bootrom.h"
#include "version_gen.h"
#include "hmi_keymap.h"
#include "drivers/i2c.hh"
#include "task_encoder.hh"
#include "task_matrix.hh"
#include "task_led.hh"
#ifdef ENABLE_DISPLAY
#include "task_display.hh"
#endif
#ifdef ENABLE_USB
#include "drivers/usb.h"
#include "tusb.h"
#endif

#define PIN_PERIPH_RESETN 22

I2C *i2c;
TaskMatrix *task_matrix;
TaskEncoder *task_encoder;
TaskLED *task_led;

#ifdef ENABLE_DISPLAY
TaskDisplay *task_display;
#endif

void main_task(void *unused);
void usb_task(void *unused);

int main(void)
{
  stdout_uart_init();

  #ifdef ENABLE_USB
  usb_init();
  #endif

  gpio_init(PIN_PERIPH_RESETN);
  gpio_set_dir(PIN_PERIPH_RESETN, GPIO_OUT);
  gpio_pull_up(PIN_PERIPH_RESETN);
  gpio_put(PIN_PERIPH_RESETN, 0);
  sleep_ms(100);
  gpio_put(PIN_PERIPH_RESETN, 1);

#ifdef ENABLE_DISPLAY
  task_display = new TaskDisplay();
  task_display->init();
#endif

  i2c = new I2C();
  i2c->init();
  task_encoder = new TaskEncoder();
  task_encoder->init();

  task_matrix = new TaskMatrix();
  task_matrix->init(i2c);

  task_led = new TaskLED();
  task_led->init(i2c);

  BaseType_t matrix_task_status = xTaskCreate(task_matrix->task, "MATRIX_TASK", 256, (void *)task_matrix, 4, nullptr);
  BaseType_t encoder_task_status = xTaskCreate(task_encoder->task, "ENCODER_TASK", 256, (void *)task_encoder, 4, nullptr);
  BaseType_t led_task_status = xTaskCreate(task_led->task, "LED_TASK", 256, (void *)task_led, 2, nullptr);
#ifdef ENABLE_DISPLAY
  BaseType_t display_gui_status = xTaskCreate(task_display->gui_task, "DISPLAY_GUI_TASK", 4096, (void *)task_display, 3, nullptr);
#endif
#ifdef ENABLE_USB
  BaseType_t usb_task_status = xTaskCreate(usb_task, "USB_TASK", 2048, nullptr, 1, nullptr);
#endif
  BaseType_t main_task_status = xTaskCreate(main_task, "MAIN_TASK", 2048, nullptr, 1, nullptr);

  assert(main_task_status == pdPASS && led_task_status == pdPASS && matrix_task_status == pdPASS && encoder_task_status == pdPASS
#ifdef ENABLE_USB
         && usb_task_status
#endif
#ifdef ENABLE_DISPLAY
         && display_gui_status == pdPASS
#endif
  );

  vTaskStartScheduler();

  while (true)
  {
    // forever
  }
}

void usb_task(void *unused)
{

  while (true)
  {
#ifdef ENABLE_USB
    usb_periodic();
#endif
    vTaskDelay(1);
  }
}

void set_ring_led(uint8_t ring, uint8_t value, uint32_t color = 0xFF0000, bool now = false)
{
  TaskLED::cmd_t cmd;
  cmd.cmd = TaskLED::LED_CMD_SET_RING;
  cmd.led = ring;
  cmd.value = value;
  cmd.color = color;
  cmd.update_now = now;
  xQueueSend(task_led->cmd_queue, &cmd, 0);
}

void set_simple_led(uint8_t led, uint8_t value, uint8_t mode = TaskLED::NORMAL, bool now = false)
{
  TaskLED::cmd_t cmd;
  cmd.cmd = TaskLED::LED_CMD_SET_SIMPLE_LED;
  cmd.led = led;
  cmd.value = value;
  cmd.mode = mode;
  cmd.update_now = now;
  xQueueSend(task_led->cmd_queue, &cmd, 0);
}

// Pre-format and publish jog overlay data for the display task.
// All float formatting happens here on the main_task stack (large),
// never on the gui_task stack (limited).
static void publish_jog_overlay(uint8_t axis, bool continuous, const float pos[3], int8_t speed_level = 0)
{
  static const char *const axis_names[3] = { "X", "Y", "Z" };
  int sel = (axis >= 1 && axis <= 3) ? axis - 1 : 0;
  // top_text is just the axis letter (rendered in big font by gui_task).
  snprintf(task_display->jog_overlay.top_text,
           sizeof(task_display->jog_overlay.top_text),
           "%s", axis_names[sel]);
  snprintf(task_display->jog_overlay.pos_text,
           sizeof(task_display->jog_overlay.pos_text),
           "%+.4f", (double)pos[sel]);
  task_display->jog_overlay.axis        = axis;
  task_display->jog_overlay.continuous   = continuous;
  task_display->jog_overlay.speed_level  = speed_level;
  task_display->jog_overlay.dirty        = true;   // must be last
}

void set_led_interp_state(interp_t state, bool step_mode = false, bool paused = false)
{
  switch (state)
  {
  case INTERP_IDLE:
    set_simple_led(LED_SINGLE_STEP, 0, TaskLED::NORMAL);
    set_simple_led(LED_PAUSE, 0, TaskLED::NORMAL);
    set_simple_led(LED_STOP, 64, TaskLED::NORMAL);
    set_simple_led(LED_CYCLE_START, 0, TaskLED::NORMAL, true);
    break;
  case INTERP_READING:
    if (step_mode)
    {
      TaskLED::modes m = paused ? TaskLED::BLINK : TaskLED::NORMAL;
      set_simple_led(LED_SINGLE_STEP, 64, m);
      set_simple_led(LED_PAUSE, 0, TaskLED::NORMAL);
      set_simple_led(LED_STOP, 0, TaskLED::NORMAL);
      set_simple_led(LED_CYCLE_START, 64, m, true);
    }
    else
    {
      // Normal run: Cycle Start LED solid.
      set_simple_led(LED_SINGLE_STEP, 0, TaskLED::NORMAL);
      set_simple_led(LED_PAUSE, 0, TaskLED::NORMAL);
      set_simple_led(LED_STOP, 0, TaskLED::NORMAL);
      set_simple_led(LED_CYCLE_START, 64, TaskLED::NORMAL, true);
    }
    break;
  case INTERP_PAUSED:
    if (step_mode)
    {
      TaskLED::modes m = paused ? TaskLED::BLINK : TaskLED::NORMAL;
      set_simple_led(LED_SINGLE_STEP, 64, m);
      set_simple_led(LED_PAUSE, 0, TaskLED::NORMAL);
      set_simple_led(LED_STOP, 0, TaskLED::NORMAL);
      set_simple_led(LED_CYCLE_START, 64, m, true);
    }
    else
    {
      // Mid-run pause — blink Pause + Cycle Start LEDs.
      set_simple_led(LED_SINGLE_STEP, 0, TaskLED::NORMAL);
      set_simple_led(LED_PAUSE, 64, TaskLED::BLINK);
      set_simple_led(LED_STOP, 0, TaskLED::NORMAL);
      set_simple_led(LED_CYCLE_START, 64, TaskLED::BLINK, true);
    }
    break;
  case INTERP_WAITING:
    if (step_mode)
    {
      TaskLED::modes m = paused ? TaskLED::BLINK : TaskLED::NORMAL;
      set_simple_led(LED_SINGLE_STEP, 64, m);
      set_simple_led(LED_PAUSE, 0, TaskLED::NORMAL);
      set_simple_led(LED_STOP, 0, TaskLED::NORMAL);
      set_simple_led(LED_CYCLE_START, 64, m, true);
    }
    else
    {
      // Normal run: waiting for motion queue — Cycle Start stays solid.
      set_simple_led(LED_SINGLE_STEP, 0, TaskLED::NORMAL);
      set_simple_led(LED_PAUSE, 0, TaskLED::NORMAL);
      set_simple_led(LED_STOP, 0, TaskLED::NORMAL);
      set_simple_led(LED_CYCLE_START, 64, TaskLED::NORMAL, true);
    }
    break;
  default:
    set_simple_led(LED_SINGLE_STEP, 0, TaskLED::NORMAL);
    set_simple_led(LED_PAUSE, 0, TaskLED::NORMAL);
    set_simple_led(LED_STOP, 0, TaskLED::NORMAL);
    set_simple_led(LED_CYCLE_START, 0, TaskLED::NORMAL, true);
  }
}

void set_led_selected_increment(uint8_t increment)
{
  switch (increment)
  {
  case 1:
    set_simple_led(LED_INCR_LG, 32);
    set_simple_led(LED_INCR_MD, 0);
    set_simple_led(LED_INCR_SM, 0, TaskLED::NORMAL, true);
    break;
  case 2:
    set_simple_led(LED_INCR_LG, 0, TaskLED::NORMAL);
    set_simple_led(LED_INCR_MD, 32, TaskLED::NORMAL);
    set_simple_led(LED_INCR_SM, 0, TaskLED::NORMAL, true);
    break;
  case 3:
    set_simple_led(LED_INCR_LG, 0, TaskLED::NORMAL);
    set_simple_led(LED_INCR_MD, 0, TaskLED::NORMAL);
    set_simple_led(LED_INCR_SM, 32, TaskLED::NORMAL, true);
    break;
  default:
    set_simple_led(LED_INCR_LG, 0, TaskLED::NORMAL);
    set_simple_led(LED_INCR_MD, 0, TaskLED::NORMAL);
    set_simple_led(LED_INCR_SM, 0, TaskLED::NORMAL, true);
    break;
  }
}

void set_led_selected_axis(uint8_t axis)
{
  switch (axis)
  {
  case 1:
    set_simple_led(LED_AXIS_X, 32, TaskLED::NORMAL);
    set_simple_led(LED_AXIS_Y, 0, TaskLED::NORMAL);
    set_simple_led(LED_AXIS_Z, 0, TaskLED::NORMAL, true);
    break;
  case 2:
    set_simple_led(LED_AXIS_X, 0, TaskLED::NORMAL);
    set_simple_led(LED_AXIS_Y, 32, TaskLED::NORMAL);
    set_simple_led(LED_AXIS_Z, 0, TaskLED::NORMAL, true);
    break;
  case 3:
    set_simple_led(LED_AXIS_X, 0, TaskLED::NORMAL);
    set_simple_led(LED_AXIS_Y, 0, TaskLED::NORMAL);
    set_simple_led(LED_AXIS_Z, 32, TaskLED::NORMAL, true);
    break;
  default:
    set_simple_led(LED_AXIS_X, 0, TaskLED::NORMAL);
    set_simple_led(LED_AXIS_Y, 0, TaskLED::NORMAL);
    set_simple_led(LED_AXIS_Z, 0, TaskLED::NORMAL, true);
    break;
  }
}

void set_encoder_value(uint8_t encoder, int8_t value, bool smart = false)
{
  TaskEncoder::cmd_t cmd;
  cmd.cmd = smart ? TaskEncoder::ENCODER_CMD_SMART_SET_VALUE : TaskEncoder::ENCODER_CMD_SET_VALUE;
  cmd.encoder = encoder;
  cmd.value = value;

  if (xQueueSend(task_encoder->cmd_queue, &cmd, pdMS_TO_TICKS(2)) != pdTRUE)
  {
    printf("encoder cmd queue full: encoder=%d value=%d smart=%d\n", encoder, value, smart ? 1 : 0);
  }
}

volatile bool g_machine_alive = false;
  

#ifdef ENABLE_DISPLAY
// Pack current machine state into a display command and enqueue it.
static inline void display_send_machine_state(
    bool estop, bool enabled, bool homed, bool coolant,
    mode_t mode, interp_t interp, bool step_mode, bool paused,
    uint8_t feed_seg, uint8_t rapid_seg, uint8_t maxvel_seg)
{
  TaskDisplay::cmd_t dcmd;
  dcmd.cmd                  = estop ? TaskDisplay::DISPLAY_CMD_ESTOP
                                    : TaskDisplay::DISPLAY_CMD_MACHINE_STATE;
  dcmd.state.estop          = estop;
  dcmd.state.enabled        = enabled;
  dcmd.state.homed          = homed;
  dcmd.state.coolant        = coolant;
  dcmd.state.mode           = mode;
  dcmd.state.interp_state   = interp;
  dcmd.state.step_mode      = step_mode;
  dcmd.state.paused         = paused;
  dcmd.state.feed_seg       = feed_seg;
  dcmd.state.rapid_seg      = rapid_seg;
  dcmd.state.maxvel_seg     = maxvel_seg;
  xQueueSend(task_display->cmd_queue, &dcmd, 0);
}
#endif

// Firmware version struct with magic marker for .uf2 scanning.
// extern "C" + named section prevents C++ inlining/stripping.
extern "C" const volatile struct __attribute__((packed)) {
    uint32_t magic;     // 0x56455221 = "VER!"
    uint8_t  major;
    uint8_t  minor;
    uint16_t build;
    char     hash[8];
    uint8_t  dirty;
} fw_version __attribute__((used, section(".rodata.fw_version"))) = {
    0x56455221,
    FW_VERSION_MAJOR, FW_VERSION_MINOR, FW_VERSION_BUILD,
    FW_VERSION_HASH, FW_VERSION_DIRTY
};

void main_task(void *unused)
{
  printf("Pico CNC HMI v%s (build %d)\n", FW_VERSION_STRING, fw_version.build);

#ifdef ENABLE_USB
  // Populate the USB feature report so the host can query the version
  // without requiring the full control protocol (heartbeat etc.).
  usb_version_report.major = FW_VERSION_MAJOR;
  usb_version_report.minor = FW_VERSION_MINOR;
  usb_version_report.build = FW_VERSION_BUILD;
  strncpy(usb_version_report.hash, FW_VERSION_HASH, sizeof(usb_version_report.hash));
  usb_version_report.dirty = FW_VERSION_DIRTY;
#endif

  bool usb_in_pending = false;
  bool key_updated = false;
  uint8_t selected_axis = 1;
  uint8_t selected_increment = 2;
  uint8_t motion_command = 0;

  const uint32_t jog_increments[] = {0, 100, 10, 1};

  uint8_t keybuf[6] = {0, 0, 0, 0, 0, 0};
  uint8_t modifiers = 0;
  bool sec_a_shift = false;          // true while Section A wide modifier key is held
  bool sec_a_shift_used = false;     // true if another key was pressed while shift held (tap-vs-hold)
  bool pending_space_release = false;  // auto-release Space on next iteration after tap
  uint8_t pressed_hid[0x60] = {};   // maps matrix code -> HID keycode sent on press (for correct release)

  usb_out_pkt last_out_pkt;

  bool machine_state_changed = false;
  bool machine_estop = true;
  bool machine_enabled = false;
  interp_t machine_interp_state = INTERP_OFF;
  bool machine_step_mode = false;
  bool machine_paused = false;
  bool machine_coolant = false;
  bool machine_optional_stop = false;
  bool machine_homed = false;
  float g_machine_pos[3] = {0.0f, 0.0f, 0.0f};
  bool  last_jog_continuous = false;  // set by most recent enc 0/4 event
  bool  shuttle_active      = false;  // true while shuttle is held at non-zero position
  int8_t shuttle_speed_level = 0;     // raw shuttle position -7..+7, for display speed bar

  TickType_t slow_blink_last = 0;
  bool slow_blink_on = false;

  mode_t machine_mode = MODE_UNKNOWN;

  bool initial_feedrate = false;
  bool initial_rapidrate = false;
  bool initial_maxvel = false;

  // Per-encoder flag: set when the user physically moves (or button-toggles) a
  // knob.  While false, host feedback changes are re-synced immediately to the
  // encoder so that LinuxCNC's startup settling packets don't leave the encoder
  // stuck at a transient 0 value.  Reset to false at each reconnect.
  bool enc_user_moved[4] = {false, false, false, false};

  // STOP + CYCLE START hold-to-home chord state.
  // Active only when: !machine_estop && machine_enabled && !machine_homed.
  // Sequence: press STOP, then press START while STOP held, hold both ≥ 2s → HOME ALL.
  bool       chord_stop_held   = false;  // STOP (0x35) currently pressed
  bool       chord_start_held  = false;  // START (0x36) currently pressed while STOP held
  bool       chord_fired       = false;  // chord completed; suppress release bits
  TickType_t chord_start_time  = 0;      // tick when both STOP+START were first held together

  bzero(&last_out_pkt, sizeof(last_out_pkt));

  const uint32_t dot_colors[] = {
      WS2812::urgb_u32(0x3f, 0x1f, 0),
      WS2812::urgb_u32(0, 0x3f, 0x3f),
      WS2812::urgb_u32(0x3f, 0, 0x3f),
  };

  TimerHandle_t hbeat_timer = xTimerCreate("hbeat_timer", pdMS_TO_TICKS(1000), pdFALSE, (void *)0, [](TimerHandle_t xTimer) {
    g_machine_alive = false;
  });

  while (true)
  {
    if (g_machine_alive) {
      #ifdef ENABLE_USB
      machine_state_changed = false;
      usb_out_pkt out_pkt;
      if (xQueueReceive(usb_out_queue, &out_pkt, 1) == pdTRUE)
      {
        usb_dump_out_pkt(&out_pkt);

        // Check for special commands before normal state processing.
        if (out_pkt.s.cmd == 0xB0) {
          printf("BOOTSEL reboot requested by host!\n");
#ifdef ENABLE_DISPLAY
          TaskDisplay::cmd_t dcmd;
          dcmd.cmd = TaskDisplay::DISPLAY_CMD_BOOTSEL;
          snprintf(dcmd.bootsel_text, sizeof(dcmd.bootsel_text), "Copy .uf2 to flash");
          xQueueSend(task_display->cmd_queue, &dcmd, 0);
          vTaskDelay(pdMS_TO_TICKS(200));  // let display task render + flush
#endif
          reset_usb_boot(0, 0);
          // does not return
        }
        if (out_pkt.s.heartbeat != last_out_pkt.s.heartbeat)
        {
          xTimerReset(hbeat_timer, 0);
          g_machine_alive = true;
          if (usb_out_queue_drops > 0) {
            printf("usb: %lu OUT packets dropped\n", (unsigned long)usb_out_queue_drops);
            usb_out_queue_drops = 0;
          }
        }

        if (out_pkt.s.estop != machine_estop)
        {
          printf("machine_estop %d -> %d\n", machine_estop, out_pkt.s.estop);
          machine_estop = out_pkt.s.estop;
          machine_state_changed = true;
        }

        if (out_pkt.s.enabled != machine_enabled)
        {
          printf("machine_enabled %d -> %d\n", machine_enabled, out_pkt.s.enabled);
          machine_enabled = out_pkt.s.enabled;
          machine_state_changed = true;
        }

        if (out_pkt.s.mode != machine_mode)
        {
          printf("machine_mode %d -> %d\n", machine_mode, out_pkt.s.mode);
          machine_mode = (mode_t)out_pkt.s.mode;
          machine_state_changed = true;
        }

        if (out_pkt.s.interp_state != machine_interp_state)
        {
          printf("machine_interp_state %d -> %d\n", machine_interp_state, out_pkt.s.interp_state);
          machine_interp_state = (interp_t)out_pkt.s.interp_state;
          machine_state_changed = true;
        }

        if (out_pkt.s.step_mode != machine_step_mode)
        {
          printf("machine_step_mode %d -> %d\n", machine_step_mode, out_pkt.s.step_mode);
          machine_step_mode = out_pkt.s.step_mode;
          machine_state_changed = true;
        }

        if (out_pkt.s.paused != machine_paused)
        {
          printf("machine_paused %d -> %d\n", machine_paused, out_pkt.s.paused);
          machine_paused = out_pkt.s.paused;
          machine_state_changed = true;
        }

        if (out_pkt.s.coolant != machine_coolant)
        {
          printf("machine_coolant %d -> %d\n", machine_coolant, out_pkt.s.coolant);
          machine_coolant = out_pkt.s.coolant;
          machine_state_changed = true;
        }

        if (out_pkt.s.optional_stop != machine_optional_stop)
        {
          printf("machine_optional_stop %d -> %d\n", machine_optional_stop, out_pkt.s.optional_stop);
          machine_optional_stop = out_pkt.s.optional_stop;
          machine_state_changed = true;
        }

        if (out_pkt.s.homed != machine_homed)
        {
          printf("machine_homed %d -> %d\n", machine_homed, out_pkt.s.homed);
          machine_homed = out_pkt.s.homed;
          machine_state_changed = true;
        }

        // Update cached axis positions for jog overlay display.
        bool pos_changed = (out_pkt.s.pos_x != last_out_pkt.s.pos_x ||
                            out_pkt.s.pos_y != last_out_pkt.s.pos_y ||
                            out_pkt.s.pos_z != last_out_pkt.s.pos_z);
        g_machine_pos[0] = out_pkt.s.pos_x * (1.0f / 10000.0f);
        g_machine_pos[1] = out_pkt.s.pos_y * (1.0f / 10000.0f);
        g_machine_pos[2] = out_pkt.s.pos_z * (1.0f / 10000.0f);
#ifdef ENABLE_DISPLAY
        // Only push position feedback while the shuttle is actively at a non-zero
        // position. This ensures the overlay timer is driven by physical user input
        // (encoder events), not by position feedback that may trickle in after the
        // shuttle returns to neutral due to simulator settling or following-error noise.
        if (pos_changed && shuttle_active &&
            !machine_estop && machine_enabled && machine_mode == MODE_MANUAL) {
          // printf("[main] pos-feedback JOG: shuttle_active=%d pos=%.4f,%.4f,%.4f\n",
          //     (int)shuttle_active, (double)g_machine_pos[0], (double)g_machine_pos[1], (double)g_machine_pos[2]);
          // Update jog overlay via shared dirty-flag (no queue, no overflow).
          publish_jog_overlay(selected_axis, true, g_machine_pos, shuttle_speed_level);
        }
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

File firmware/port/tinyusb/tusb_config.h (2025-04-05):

/*
 * The MIT License (MIT)
 *
 * Copyright (c) 2019 Ha Thach (tinyusb.org)
 *
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
 */

#ifndef _TUSB_CONFIG_H_
#define _TUSB_CONFIG_H_

#ifdef __cplusplus
 extern "C" {
#endif

//--------------------------------------------------------------------+
// Board Specific Configuration
//--------------------------------------------------------------------+

// RHPort number used for device can be defined by board.mk, default to port 0
#ifndef BOARD_TUD_RHPORT
#define BOARD_TUD_RHPORT      0
#endif

// RHPort max operational speed can defined by board.mk
#ifndef BOARD_TUD_MAX_SPEED
#define BOARD_TUD_MAX_SPEED   OPT_MODE_DEFAULT_SPEED
#endif

//--------------------------------------------------------------------
// COMMON CONFIGURATION
//--------------------------------------------------------------------

// defined by compiler flags for flexibility
#ifndef CFG_TUSB_MCU
#error CFG_TUSB_MCU must be defined
#endif

#ifndef CFG_TUSB_OS
#define CFG_TUSB_OS           OPT_OS_NONE
#endif


#ifndef CFG_TUSB_DEBUG
#define CFG_TUSB_DEBUG        0
#endif

// Enable Device stack
#define CFG_TUD_ENABLED       1

// Default is max speed that hardware controller could support with on-chip PHY
#define CFG_TUD_MAX_SPEED     BOARD_TUD_MAX_SPEED

/* USB DMA on some MCUs can only access a specific SRAM region with restriction on alignment.
 * Tinyusb use follows macros to declare transferring memory so that they can be put
 * into those specific section.
 * e.g
 * - CFG_TUSB_MEM SECTION : __attribute__ (( section(".usb_ram") ))
 * - CFG_TUSB_MEM_ALIGN   : __attribute__ ((aligned(4)))
 */
#ifndef CFG_TUSB_MEM_SECTION
#define CFG_TUSB_MEM_SECTION
#endif

#ifndef CFG_TUSB_MEM_ALIGN
#define CFG_TUSB_MEM_ALIGN        __attribute__ ((aligned(4)))
#endif

//--------------------------------------------------------------------
// DEVICE CONFIGURATION
//--------------------------------------------------------------------

#ifndef CFG_TUD_ENDPOINT0_SIZE
#define CFG_TUD_ENDPOINT0_SIZE    64
#endif

//------------- CLASS -------------//
#define CFG_TUD_HID               2
#define CFG_TUD_CDC               0
#define CFG_TUD_MSC               0
#define CFG_TUD_MIDI              0
#define CFG_TUD_VENDOR            0

// HID buffer size Should be sufficient to hold ID (if any) + Data
#define CFG_TUD_HID_EP_BUFSIZE    64

#ifdef __cplusplus
 }
#endif

#endif /* _TUSB_CONFIG_H_ */

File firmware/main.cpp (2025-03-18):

// PICO 2 GPIO MAP HW REV0
// =======================
// GPIO  0 - UART0 TX
// GPIO  1 - UART0 RX
// GPIO  2 - SPI0_SCK
// GPIO  3 - SPI0_DOUT
// GPIO  4 - LCD_A0
// GPIO  5 - SPI0_CS0
// GPIO  6 - JOG_A
// GPIO  7 - JOG_B
// GPIO  8 - SHUTTLE_0
// GPIO  9 - SHUTTLE_1
// GPIO 10 - SHUTTLE_2
// GPIO 11 - SHUTTLE_3
// GPIO 12 - ENC0_A
// GPIO 13 - ENC0_B
// GPIO 14 - ENC1_A
// GPIO 15 - ENC1_B
// GPIO 16 - ENC2_A
// GPIO 17 - ENC2_B
// GPIO 18 - SPARE
// GPIO 19 - /KEY_INT
// GPIO 20 - I2C0_SDA
// GPIO 21 - I2C0_SCL
// GPIO 22 - /PERIPH_RESET
// GPIO 26 - SPARE
// GPIO 27 - SPARE
// GPIO 28 - SPARE

#include <stdlib.h>
#include <stdio.h>
#include <string.h>

#include "bsp/board_api.h"
#include "tusb.h"
#include "encoder.hh"

/* Blink pattern
 * - 250 ms  : device not mounted
 * - 1000 ms : device mounted
 * - 2500 ms : device is suspended
 */
enum  {
  BLINK_NOT_MOUNTED = 250,
  BLINK_MOUNTED = 1000,
  BLINK_SUSPENDED = 2500,
};

static uint32_t blink_interval_ms = BLINK_NOT_MOUNTED;


void led_blinking_task(void);

union pkt_u {
  struct pkt_s {
    int knob1;
    int knob2;
    int knob3;
    uint8_t button1;
    uint8_t button2;
    uint8_t button3;
  } s;
  unsigned char buf[64];
} pkt;

int main(void)
{
  Encoder encoders;

  board_init();
  tud_init(BOARD_TUD_RHPORT);

  if (board_init_after_tusb) {
    board_init_after_tusb();
  }
  
  encoders.init();
  
  //gpio_init(ENCODER_1_PIN_BUTTON);
  //gpio_set_dir(ENCODER_1_PIN_BUTTON, GPIO_IN);
  //gpio_pull_up(ENCODER_1_PIN_BUTTON);
    //bool btn = gpio_get(ENCODER_1_PIN_BUTTON);
    //if ( btn != last_btn_1) {
    //  last_btn_1 = btn;
    //  update = true;
    //} 

  while (1)
  {

    tud_task();
    led_blinking_task();

    if (encoders.task()) {
      pkt.s.knob1 = encoders.value(0);
      pkt.s.knob2 = encoders.value(1);
      pkt.s.knob3 = encoders.value(2);
      pkt.s.button1 = 0;
      pkt.s.button2 = 0;
      pkt.s.button3 = 0;

      tud_hid_report(0, &pkt, sizeof(pkt));
    }
  }
}

//--------------------------------------------------------------------+
// Device callbacks
//--------------------------------------------------------------------+

// Invoked when device is mounted
void tud_mount_cb(void)
{
  blink_interval_ms = BLINK_MOUNTED;
}

// Invoked when device is unmounted
void tud_umount_cb(void)
{
  blink_interval_ms = BLINK_NOT_MOUNTED;
}

// Invoked when usb bus is suspended
// remote_wakeup_en : if host allow us  to perform remote wakeup
// Within 7ms, device must draw an average of current less than 2.5 mA from bus
void tud_suspend_cb(bool remote_wakeup_en)
{
  (void) remote_wakeup_en;
  blink_interval_ms = BLINK_SUSPENDED;
}

// Invoked when usb bus is resumed
void tud_resume_cb(void)
{
  blink_interval_ms = tud_mounted() ? BLINK_MOUNTED : BLINK_NOT_MOUNTED;
}

//--------------------------------------------------------------------+
// USB HID
//--------------------------------------------------------------------+

// Invoked when received GET_REPORT control request
// Application must fill buffer report's content and return its length.
// Return zero will cause the stack to STALL request
uint16_t tud_hid_get_report_cb(uint8_t itf, uint8_t report_id, hid_report_type_t report_type, uint8_t* buffer, uint16_t reqlen)
{
  // TODO not Implemented
  (void) itf;
  (void) report_id;
  (void) report_type;
  (void) buffer;
  (void) reqlen;

  return 0;
}

// Invoked when received SET_REPORT control request or
// received data on OUT endpoint ( Report ID = 0, Type = 0 )
void tud_hid_set_report_cb(uint8_t itf, uint8_t report_id, hid_report_type_t report_type, uint8_t const* buffer, uint16_t bufsize)
{
  // This example doesn't use multiple report and report ID
  (void) itf;
  (void) report_id;
  (void) report_type;

  // echo back anything we received from host
  // tud_hid_report(0, buffer, bufsize);
}

//--------------------------------------------------------------------+
// BLINKING TASK
//--------------------------------------------------------------------+
void led_blinking_task(void)
{
  static uint32_t start_ms = 0;
  static bool led_state = false;

  // Blink every interval ms
  if ( board_millis() - start_ms < blink_interval_ms) return; // not enough time
  start_ms += blink_interval_ms;

  board_led_write(led_state);
  led_state = 1 - led_state; // toggle
}

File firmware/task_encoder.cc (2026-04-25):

#include <stdio.h>
#include <stdlib.h>
#include "task_encoder.hh"

TaskEncoder::TaskEncoder()
{
  event_queue = xQueueCreate(10, sizeof(event_t));
  cmd_queue = xQueueCreate(10, sizeof(cmd_t));

  m_mutex = xSemaphoreCreateMutex();

  for (int i = 0; i < 5; i++)
    m_last_value[i] = 0;
}

TaskEncoder::~TaskEncoder()
{
}

void TaskEncoder::init()
{
  m_encoders.init();

  m_encoders.set_limits(0, 0, 0, 4);  // jog wheel: div=4 so 1 physical click = 1 count
  m_encoders.set_limits(1, 0, 14, 4);
  m_encoders.set_limits(2, 0, 14, 4);
  m_encoders.set_limits(3, 0, 14, 4);
}

int TaskEncoder::get_value(uint8_t encoder, bool raw)
{
  xSemaphoreTake(m_mutex, portMAX_DELAY);
  int value = m_encoders.value(encoder);
  xSemaphoreGive(m_mutex);

  return value;
}

void TaskEncoder::sync_all_immediate(int enc1, int enc2, int enc3)
{
  xSemaphoreTake(m_mutex, portMAX_DELAY);
  m_encoders.set_value(1, enc1);
  m_encoders.set_value(2, enc2);
  m_encoders.set_value(3, enc3);
  // Update shadow values so change-detection in task() sees no delta —
  // suppressing the spurious "0 → N" event that would otherwise fire the
  // next time the encoder task polls after a reconnect.
  m_last_value[1] = enc1;
  m_last_value[2] = enc2;
  m_last_value[3] = enc3;
  printf("sync_all_immediate: enc1=%d enc2=%d enc3=%d => v1=%d v2=%d v3=%d\n",
         enc1, enc2, enc3,
         m_encoders.value(1), m_encoders.value(2), m_encoders.value(3));
  xSemaphoreGive(m_mutex);
}

void TaskEncoder::sync_value_immediate(uint8_t encoder, int value)
{
  xSemaphoreTake(m_mutex, portMAX_DELAY);
  m_encoders.set_value(encoder, value);
  m_last_value[encoder] = value;
  printf("sync_value_immediate: enc=%d value=%d => v=%d\n",
         encoder, value, m_encoders.value(encoder));
  xSemaphoreGive(m_mutex);
}

void TaskEncoder::task(void *param)
{
  TaskEncoder* inst = static_cast<TaskEncoder*>(param);
  
  Encoder &encoders = inst->m_encoders;

  bool force_encoder_update = false;

  // m_last_value[] is now a member (initialized to 0 in constructor) rather
  // than a local variable.  This allows sync_all_immediate() to update the
  // shadow atomically under the mutex so get_value() is immediately correct
  // after a reconnect, before this task drains the cmd queue.

  while (true)
  {
    // Drain ALL pending commands before polling hardware.
    cmd_t cmd;
    while (xQueueReceive(inst->cmd_queue, &cmd, 0) == pdTRUE)
    {
      if (cmd.cmd == ENCODER_CMD_SET_VALUE)
      {
        // Suppress the change event: write both the encoder value and the
        // shadow together under the mutex.
        xSemaphoreTake(inst->m_mutex, portMAX_DELAY);
        encoders.set_value(cmd.encoder, cmd.value);
        inst->m_last_value[cmd.encoder] = cmd.value;
        xSemaphoreGive(inst->m_mutex);
      }
      else if (cmd.cmd == ENCODER_CMD_SET_VALUE_NOTIFY)
      {
        // Like SET_VALUE but fires an encoder event so the IN packet is
        // triggered AFTER the value is applied.  Don't update m_last_value —
        // let the change detection loop below fire the event.
        xSemaphoreTake(inst->m_mutex, portMAX_DELAY);
        encoders.set_value(cmd.encoder, cmd.value);
        xSemaphoreGive(inst->m_mutex);
        force_encoder_update = true;
      }
      else if (cmd.cmd == ENCODER_CMD_SMART_SET_VALUE)
      {
        if (cmd.encoder >= 1 && cmd.encoder <= 3)
        {
          xSemaphoreTake(inst->m_mutex, portMAX_DELAY);
          int v = encoders.value(cmd.encoder);
          int min = encoders.get_min(cmd.encoder);
          int max = encoders.get_max(cmd.encoder);
          int span = max - min;

          printf("smart set encoder %d value %d min %d max %d span %d\n", cmd.encoder, v, min, max, span);

          if (v < min + span / 2) {
            encoders.set_value(cmd.encoder, max);
          } else {
            encoders.set_value(cmd.encoder, min);
          }
          xSemaphoreGive(inst->m_mutex);
          force_encoder_update = true;
        }
      }
    }

    // Poll hardware and fire change events, all under the mutex so that
    // sync_all_immediate() from main_task cannot race with m_last_value updates.
    xSemaphoreTake(inst->m_mutex, portMAX_DELAY);
    bool upd = encoders.task();

    if (upd || force_encoder_update)
    {
      force_encoder_update = false;

      for (int i = 0; i < 5; i++)
      {
        int cur = encoders.value(i);
        if (cur != inst->m_last_value[i])
        {
          event_t evt;
          evt.encoder = i;
          evt.value = cur;
          if (xQueueSend(inst->event_queue, &evt, 0) != pdTRUE)
          {
            printf("encoder event queue full: encoder=%d value=%d\n", evt.encoder, evt.value);
          }
          inst->m_last_value[i] = cur;
        }
      }
    }
    xSemaphoreGive(inst->m_mutex);

    vTaskDelay(10);
  }
}

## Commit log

2025-02-26 hal side test
    [hmi_test.hal]
2025-03-04 reorg, adding hw design in progress
    [DSA 1u.step, DSA 2u.step, Gateron-KS33-Socket.step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]
2025-03-08 hw wip
    [REC16K25-201.stp, cnc-hmi.kicad_pcb, cnc-hmi.kicad_sch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]
2025-03-10 Commit before rev0 release to fab
    [527451496.stp, 687114183622_Download_STP_687114183622_rev1.stp, cnc-hmi.kicad_pcb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]
2025-03-10 rev0 to fab
    [cnc-hmi-B_Cu.gbr, cnc-hmi-B_Mask.gbr, cnc-hmi-B_Paste.gbr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]
2025-03-14 add encoder led board
    [B4B-PH-SM4-TBT.step, WS2812-2020.STEP, cnc-hmi-encleds.kicad_pcb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]
2025-03-15 prep for fab&assembly
    [cnc-hmi-encleds-BoM.xls, cnc-hmi-encleds-CENTROID.xls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]
2025-03-15 add wip USB/power module
    [cnc-hmi-usb-power.kicad_pcb, cnc-hmi-usb-power.kicad_sch]
2025-03-18 split encoder stuff off to class
2025-03-18 start of i2c
2025-03-19 polled-interrupt for tca8418
2025-03-19 add tlc59116 led driver support
2025-03-19 some cleanups, fix up tca8418 usage of i2c
    [i2c.cc, main.cc, tca8418.cc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]
2025-03-21 add SPI OLED SH1122 support
2025-03-22 fix signs of encoders
    [encoder.cc]
2025-03-28 encoder min/max settings
2025-03-29 smart encoder value set
2025-03-29 reworking display to task, turned OFF for now
    [main.cc]
2025-03-30 move to official Raspberry Pi port of FreeRTOS
2025-04-07 hmi integration work
    [hmi_test.hal]
2025-04-10 add blinking support to tlc59116 leds
2026-04-20 picking the project back up with my buddy Claude.
    [hmi_bridge.hal, hmi_sim.ini, hmi_sim_cmds.hal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]
2026-04-21 bunch of work improving knob/led ring and program control behaviors.
    [hmi_sim.ini, hmi_sim_cmds.hal]
2026-04-21 add homed state
    [hmi_sim_cmds.hal]
2026-04-21 some hack cleanup fixes
    [hmi_sim_cmds.hal]
2026-04-21 bump sdk and lvgl versions
    [hmi_sim_cmds.hal]
2026-04-22 several fixes
    [hmi_sim_cmds.hal]
2026-04-22 new homing feature STOP+CYCLE START
    [hmi_sim_cmds.hal]
2026-04-22 add probe basic sim
    [core_sim_3.hal, hmi_bridge.hal, hmi_wiring.hal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]
2026-04-23 feat: improve HMI step mode reliability, add auto-manual switching for jog, and refine HID interface detection
2026-04-24 rework program control logic from the ground up
    [main.cc]
2026-04-24 fix led swap
2026-04-24 BOOTSEL firmware updater: - Add cmd byte (offset 14) to OUT packet; 0xB0 triggers reset_usb_boot(). - DISPLAY_CMD_BOOTSEL shows USB Boot message before MCU reset. - linuxcnc/update_firmware.py: full 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
    [main.cc]
2026-04-24 firmware versioning: auto-generated build numbers + HID feature report
    Build system:
    - gen_version.sh generates version_gen.h from git state on every build
    (major.minor from CMakeLists.txt, build=commit count, hash, dirty flag)
    - CMake custom target runs gen_version.sh before compilation
    - version_gen.h and build/ added to .gitignore
    Firmware:
    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
2026-04-24 named LED constants, pause+cycle blink, SIGUSR2 updater
    - Add LED_SINGLE_STEP/LED_PAUSE/LED_STOP/LED_CYCLE_START defines,
    replace all magic numbers in set_led_interp_state and elsewhere.
    - Pause state now blinks Pause + Cycle Start LEDs together.
    Host:
    - hmi.py: SIGUSR2 handler sends BOOTSEL reboot command on behalf of
    the firmware updater (since hmi.py holds the HID device lock).
    - update_firmware.py: falls back to SIGUSR2 when it can't open the
    device directly, enabling updates while hmi.py is running.
    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
    [main.cc]
2026-04-24 hmi_keymap.h, display status fix, updater robustness
    - New hmi_keymap.h: named constants for all TCA8418 key codes
    (KEY_INCR_LG/MD/SM, KEY_AXIS_X/Y/Z, KEY_STOP, etc.) and TLC59116
    LED indices (LED_INCR_LG/MD/SM, LED_AXIS_X/Y/Z, etc.).
    Eliminates all magic numbers from main.cc.
    - Display status now respects step_mode in PAUSED and WAITING states:
    shows STEP instead of PAUSE/RUN when single-stepping.
    Host (update_firmware.py):
    - Detect device already in BOOTSEL mode and skip reboot/mount steps.
    - Fix regex escape warning (raw string for pgrep pattern).
    - Handle PermissionError on copy with sudo fallback.
    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
    [hmi_keymap.h, main.cc]
2026-04-24 display: dedicated overlay panels, JetBrains Mono 48px, fix LVGL deadlock
    Refactor transient overlay system from single shared panel to dedicated
    per-type panels (jog, knob, select, bootsel). Each panel has its own
    pre-configured labels and fonts, eliminating runtime style/alignment
    reconfiguration.
    Visual changes:
    - JetBrains Mono SemiBold 48px (1bpp) for overlay letter and value
    - Dim gray (0x60) axis/mode identifier, bright white value
    - Tighter horizontal spacing (4px letter, 40px value offset)
    - Drop IPM suffix from velocity overlay (fits 256px width)
    Font assets:
    - Add fonts/jetbrainsmono_48.c (48px 1bpp, ASCII 32-126)
    - Add fonts/jetbrainsmono_24.c (24px, unused but available)
    Knob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
    [main.cc]
2026-04-24 display: 4bpp fonts, JetBrains Mono 20px status row, update docs
    - Switch overlay font back to 4bpp (smoother antialiasing on grayscale OLED)
    - Add JetBrains Mono 20px 4bpp for status row overrides (monospace alignment)
    - Remove space after colon in F:/R:/V: prefixes (tighter monospace layout)
    - Update doc/todo.md: mark jog overlay + LVGL deadlock as completed with
    full root-cause analysis; remove stale 'DISABLED, TODO revisit' section
2026-04-25 Add segmented speed bar to jog overlay for shuttle speed indication
    - 14 pre-created rectangle segments (7 left/reverse, 7 right/forward)
    - Positioned at bottom of jog overlay panel, text shifted up 5px
    - Brightness ramps from dim gray (level 1) to full white (level 7)
    - Driven by raw shuttle encoder value (-7..+7) passed through jog_overlay_t
    - Hidden during incremental jog (MPG wheel) — only shown for continuous/shuttle
    [main.cc]
2026-04-25 Add incremental jog direction flash on speed bar
    - MPG wheel clicks flash all 7 segments in the jog direction for 100ms
    - Direction computed from encoder delta (+1/-1)
    - Continuous shuttle retains static bar display unchanged
    - speed_level field added to jog_overlay_t for both modes
2026-04-25 Replace wait screen with Pico CNC HMI title + version
    - Removed USB plug icon and 'Waiting for connection...' text
    - Shows 'Pico CNC HMI' (roboto_20) centered with version below (roboto_14)
    - Both labels vertically centered on the 64px display
2026-04-25 jog speeds for testing
    [pb_sim.ini]
